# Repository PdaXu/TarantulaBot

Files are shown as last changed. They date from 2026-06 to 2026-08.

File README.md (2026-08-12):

<div align="center">

# 🕷️ TarantulaBot

**A Bio-Inspired Quadrupedal Wall-Climbing Robot with Electromagnetic Adhesion and a Soft Manipulator**

*仿生四足爬壁机器人 · 电磁吸附 · 软体机械手*

<!-- 图1：整机照片（机器人贴在钢面上工作）。放这里当 hero 图，第一眼抓人。 -->
<!-- IMAGE 1: Hero shot — the robot adhered to the steel wall. This is the first thing visitors see. -->
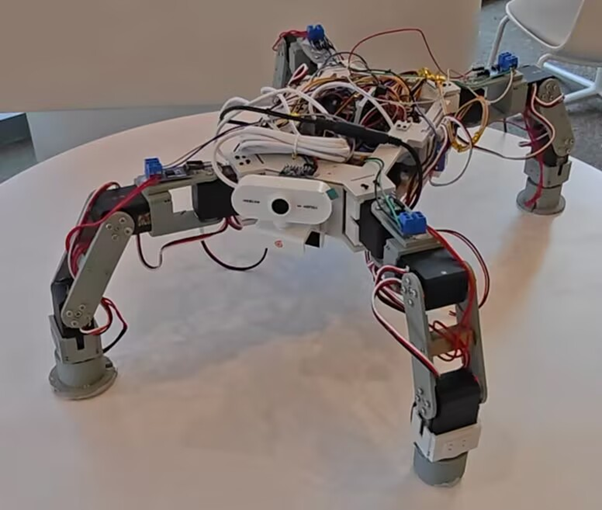
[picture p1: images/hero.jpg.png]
TarantulaBot


[English](#english) · [中文](#中文)

</div>

---

## English

### Overview

TarantulaBot is a bio-inspired quadrupedal wall-climbing robot designed to inspect and interact with ferromagnetic vertical structures such as steel towers, tanks, and I-beams. Unlike most wall-climbing platforms that are limited to passive inspection, TarantulaBot combines **legged climbing** with an **onboard soft manipulator**, so it can both traverse a surface and grasp small objects on it.

The platform integrates four subsystems on a two-tier control architecture: **the Orange Pi 5 decides, the ESP32 executes.**

<!-- 图2：系统架构框图（Orange Pi / ESP32 两层）。放在 Overview 下面，帮读者建立整体认知。 -->
<!-- IMAGE 2: System architecture diagram (two-tier Orange Pi / ESP32). Anchors the reader's mental model. -->
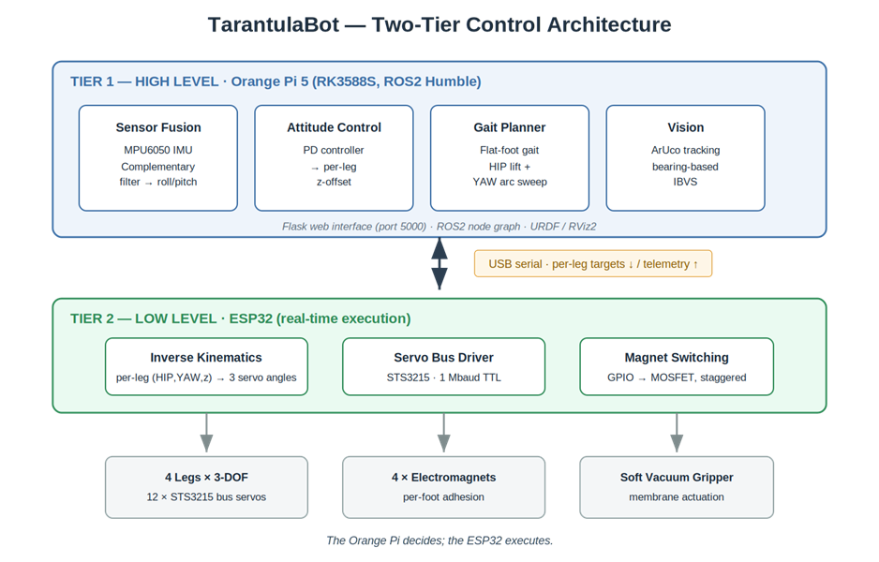
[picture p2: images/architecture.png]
System Architecture


### Key Features

- **12-DOF quadruped** — 4 legs × 3-DOF, driven by Feetech STS3215 bus servos
- **Flat-foot constrained gait** — ankle held vertical so the flat foot stays flush; each step is a HIP lift + YAW arc sweep
- **IMU attitude stabilization** — MPU6050 + complementary filter + PD, distributing a body-tilt error into per-leg height offsets (recovers a ~10° disturbance to level in ~0.40 s)
- **Per-foot electromagnetic adhesion** — MOSFET-switched, staggered activation, flyback-protected; handoff synchronized to the swing-to-stance transition
- **ArUco bearing-based visual servoing** — track a marker with no camera calibration
- **Soft vacuum-membrane manipulator** — grasps small irregular objects (keys, screws)
- **Flask web interface** — dark-theme control panel, bilingual toggle, per-leg magnet test, auto-reconnecting serial

### Demo

<!-- 图3：斜面爬行照片（标注角度 30–45°）。展示核心能力。 -->
<!-- IMAGE 3: Robot climbing the inclined steel plate (annotate 30–45°). Shows the core capability. -->
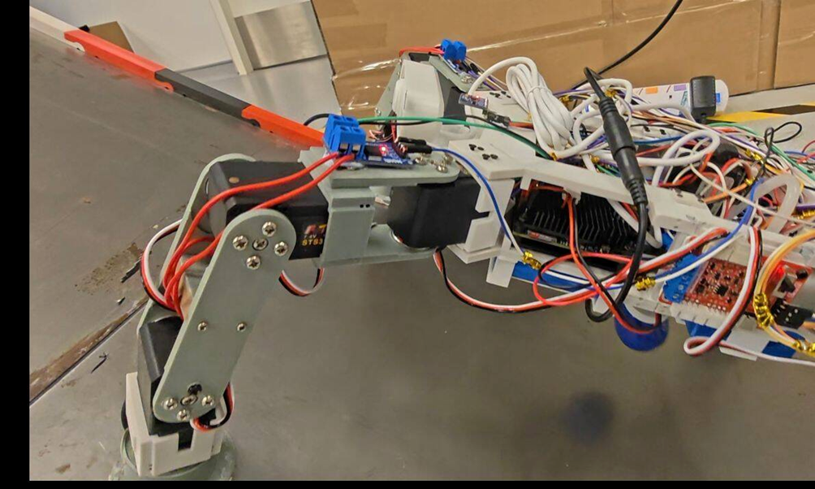
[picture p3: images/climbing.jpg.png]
Climbing demo


<!-- 图4：软夹爪抓取特写（钥匙/螺丝）。展示操作能力。 -->
<!-- IMAGE 4: Soft gripper holding a key / screw. Shows manipulation. -->
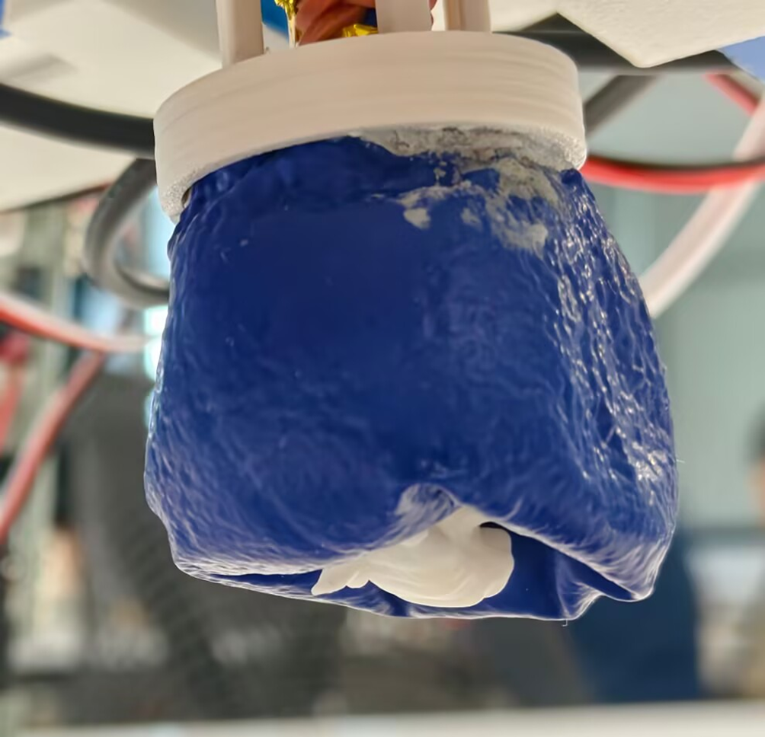
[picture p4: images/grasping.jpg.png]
Grasping demo


> 📹 A demo video is available here: `docs/demo.mp4` *(or link to your video)*

### How It Works

**Flat-foot constrained gait.** The feet are flat pads, not point contacts — a flat pad only adheres when its face is parallel to the wall. The ankle is therefore held vertical, and locomotion is produced by lifting the leg (HIP) and sweeping it in a YAW arc to the next footfall, rather than translating the foot in a straight line. Steering is differential: the left and right legs sweep by different amounts.

**Attitude control.** An MPU6050 is fused with a complementary filter (α ≈ 0.98) to estimate roll and pitch. A per-axis PD controller converts the tilt error into per-leg vertical offsets — the low side extends and the high side retracts, levelling the body since it cannot rotate itself.

<!-- 图5：IMU 姿态恢复曲线（roll/pitch 随时间，标 <1s）。有实测数据的图最有说服力。 -->
<!-- IMAGE 5: Measured PD attitude-recovery curve. Real data is the most convincing figure in the repo. -->
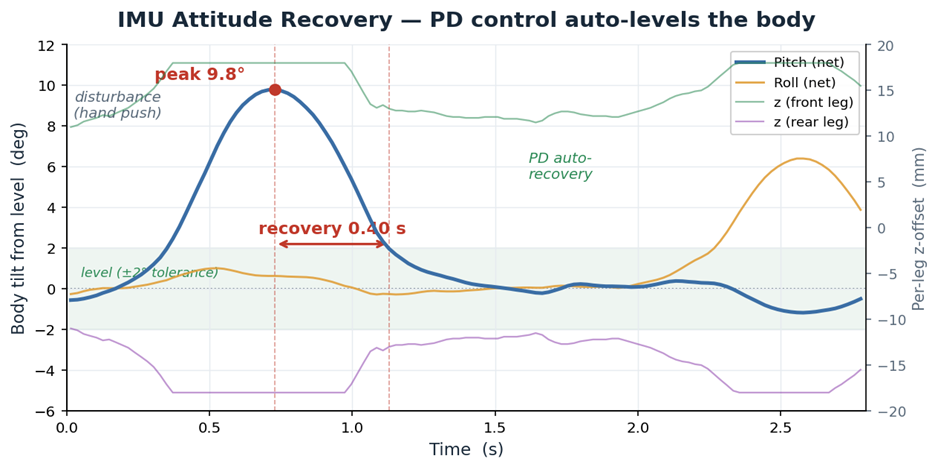
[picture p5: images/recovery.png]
Attitude recovery


**Visual servoing.** ArUco marker tracking uses the marker's horizontal pixel offset from image center as a heading error and drives it to zero — no camera intrinsics needed, because only alignment matters, not distance.

### Repository Structure

```
TarantulaBot/
├── firmware/          # ESP32 firmware (Arduino C++): servo bus + magnet switching
├── orangepi/          # High-level control (Python): IMU PD, gait, ArUco, Flask
│   ├── pid_ctrl.py    # IMU attitude PD controller
│   ├── app.py         # Flask web interface
│   └── ...
├── cad/               # 3D models (SolidWorks / STL) for legs and body plate
├── docs/              # Report, images, diagrams
└── README.md
```
> 按你的实际目录调整；上面是建议结构。

### Hardware

| Component | Detail |
|---|---|
| Compute (high-level) | Orange Pi 5 (RK3588S, ROS2 Humble) |
| Controller (low-level) | ESP32 (WROOM-32) |
| Servos | 12 × Feetech STS3215 (1 Mbaud TTL bus) |
| Adhesion | 4 × 12 V electromagnets, N-MOSFET switching, flyback diodes |
| IMU | MPU6050 (I²C) |
| Manipulator | Soft vacuum-membrane gripper + miniature pump |
| Structure | 3D-printed (PLA); SolidWorks source in `cad/` |

### Getting Started

```bash
# On the Orange Pi 5
git clone https://github.com/<your-username>/TarantulaBot.git
cd TarantulaBot/orangepi
pip install -r requirements.txt

# Flash firmware/ to the ESP32 via Arduino IDE (SCServo library required)

# Run the web control interface
python3 app.py
# then open http://<orangepi-ip>:5000 in a browser
```
> 具体命令按你的实际代码补全。

### Status & Limitations

TarantulaBot has been validated on flat ground and inclined steel up to **30–45°**, with reliable adhesion, attitude recovery, and soft-gripper grasping. **Full vertical (90°) wall-climbing was attempted but not yet achieved** — currently limited by adhesion-handoff timing, dynamic load transfer during leg swing, and structural rigidity under shear. This is the primary target for the next iteration.

### Team

**Team XD** — Xu Chenfei · Xu Pandeng
Singapore University of Technology and Design (SUTD) · Robotics and Automation (MTD)
Mentor: Prof. Pablo Valdivia y Alvarado

### License

Released under the MIT License — see [LICENSE](LICENSE). *（如果你想用别的许可，告诉我改）*

---

## 中文

### 项目简介

TarantulaBot 是一款仿生四足爬壁机器人,面向钢塔、储罐、工字梁等**铁磁性垂直结构**的巡检与作业。不同于大多数只能被动巡检的爬壁平台,TarantulaBot 把**足式攀爬**与**机载软体机械手**结合在一起——既能在表面移动,又能抓取表面上的小物件。

整机由四个子系统组成,采用两层控制架构:**Orange Pi 5 负责决策,ESP32 负责执行。**

<!-- 系统架构框图同上（图2） -->

### 核心特性

- **12 自由度四足** —— 4 腿 × 3 自由度,Feetech STS3215 总线舵机驱动
- **平足约束步态** —— 踝关节保持垂直,让平底足始终平贴表面;每步为 HIP 抬升 + YAW 弧形扫动
- **IMU 姿态稳定** —— MPU6050 + 互补滤波 + PD,将本体倾斜误差分配为每条腿的高度偏移(约 10° 扰动可在 ~0.40s 内回稳)
- **足端电磁吸附** —— MOSFET 开关、交错激活、flyback 保护;吸附时序严格同步到摆动相→支撑相切换
- **ArUco 方位视觉伺服** —— 无需相机标定即可跟踪标记
- **软体真空膜机械手** —— 抓取钥匙、螺丝等小型不规则物体
- **Flask 网页控制界面** —— 深色主题、中英切换、每条腿电磁铁独立测试、串口自动重连

### 演示

<!-- 斜面爬行图（图3）、软夹爪抓取图（图4）同上 -->

> 📹 演示视频:`docs/demo.mp4`（或替换成你的视频链接）

### 工作原理

**平足约束步态。** 足底是平垫而非点接触——平垫只有在与墙面平行时才能吸附。因此踝关节保持垂直,迈步靠抬腿(HIP)+ YAW 弧扫到下一落点实现,而不是让足直线平移。转向采用左右腿差速扫动。

**姿态控制。** MPU6050 经互补滤波(α ≈ 0.98)估计 roll/pitch,每轴 PD 控制器把倾斜误差转成每条腿的垂直偏移——低的一侧伸长、高的一侧缩短,靠不等高把本体撑平(本体自身无法旋转)。

<!-- IMU 姿态恢复曲线（图5）同上 -->

**视觉伺服。** ArUco 标记跟踪以标记中心相对图像中心的水平像素偏移作为朝向误差并将其归零——因为只关心对准、不关心距离,所以不需要相机内参。

### 目录结构

```
TarantulaBot/
├── firmware/          # ESP32 固件（Arduino C++）：舵机总线 + 电磁铁开关
├── orangepi/          # 上位机控制（Python）：IMU PD、步态、ArUco、Flask
│   ├── pid_ctrl.py    # IMU 姿态 PD 控制器
│   ├── app.py         # Flask 网页界面
│   └── ...
├── cad/               # 三维模型（SolidWorks / STL）：腿部与机身板
├── docs/              # 报告、图片、示意图
└── README.md
```
> 请按你的实际目录调整。

### 硬件清单

| 部件 | 说明 |
|---|---|
| 主控（高层） | Orange Pi 5（RK3588S，ROS2 Humble） |
| 下位机（底层） | ESP32（WROOM-32） |
| 舵机 | 12 × Feetech STS3215（1 Mbaud TTL 总线） |
| 吸附 | 4 × 12 V 电磁铁，N-MOSFET 开关，flyback 二极管 |
| IMU | MPU6050（I²C） |
| 机械手 | 软体真空膜夹爪 + 微型气泵 |
| 结构 | 3D 打印（PLA）；SolidWorks 源文件见 `cad/` |

### 快速开始

```bash
# 在 Orange Pi 5 上
git clone https://github.com/<你的用户名>/TarantulaBot.git
cd TarantulaBot/orangepi
pip install -r requirements.txt

# 用 Arduino IDE 将 firmware/ 烧录到 ESP32（需 SCServo 库）

# 运行网页控制界面
python3 app6.py
# 浏览器打开 http://<orangepi-ip>:5000
```
> 具体命令按你的实际代码补全。

### 现状与局限

TarantulaBot 已在平地和倾斜钢面(**30–45°**)上验证,吸附可靠,姿态可恢复,软夹爪抓取成功。**90° 垂直爬墙已尝试但尚未完全实现**——当前受限于吸附时序、摆动相动态载荷转移、以及剪切载荷下的结构刚性,这是下一代的首要目标。

### 团队

**Team XD** —— 徐晨飞 · 徐磐登
新加坡科技设计大学(SUTD)· 机器人与自动化(MTD)
导师:Prof. Pablo Valdivia y Alvarado

### 许可

采用 MIT 许可证,见 [LICENSE](LICENSE)。

</div>

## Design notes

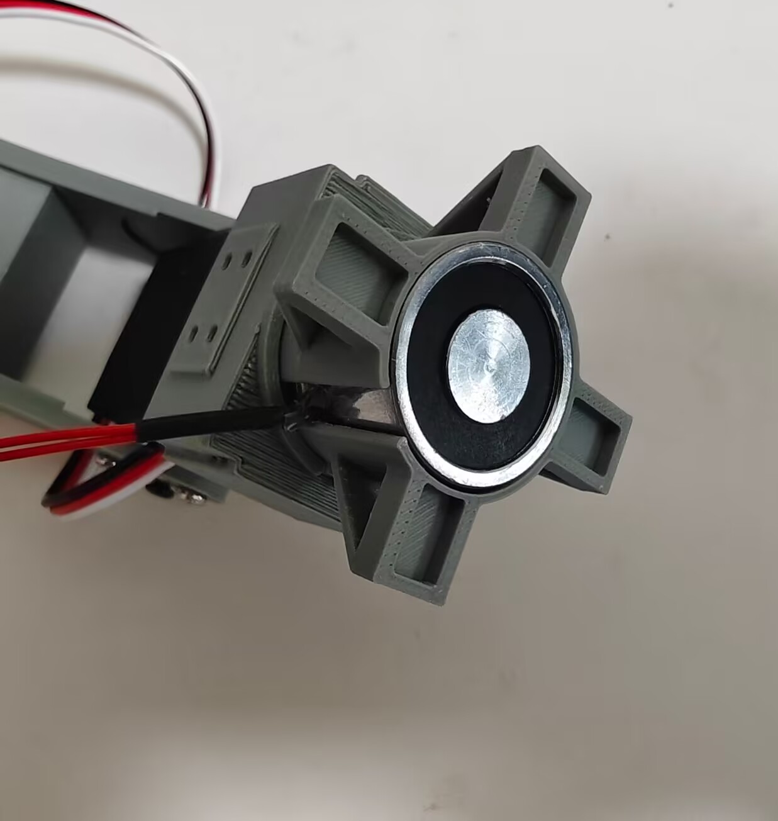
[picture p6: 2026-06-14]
assets/Foot.jpg

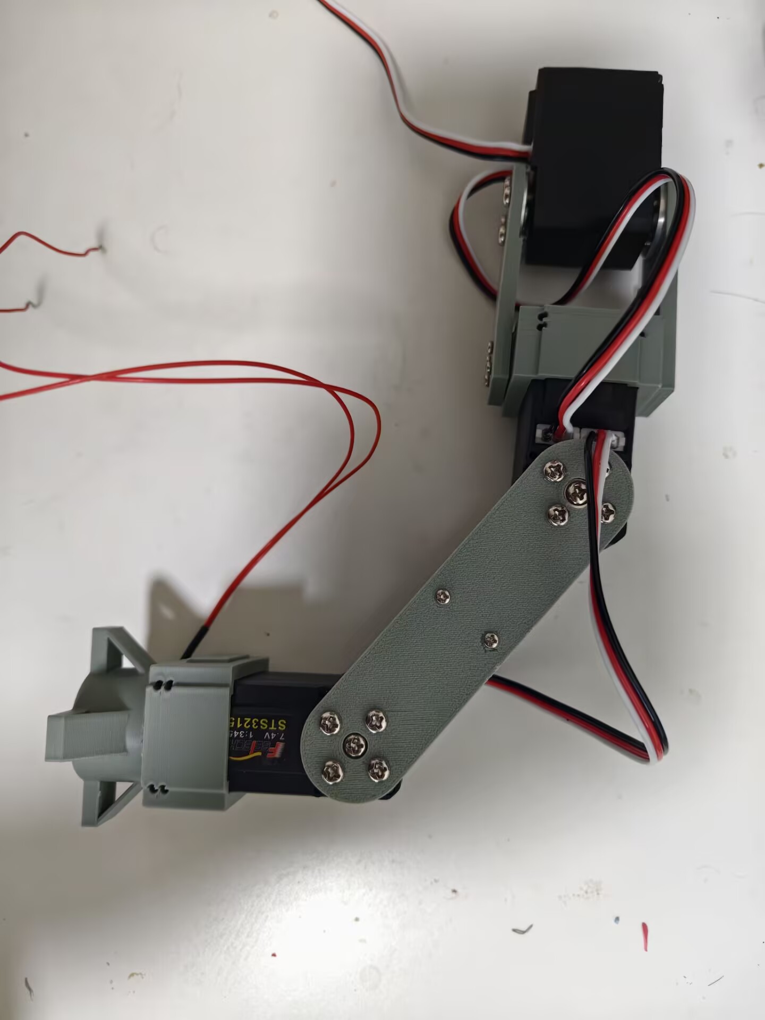
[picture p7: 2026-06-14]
assets/WholeoneLeg.jpg

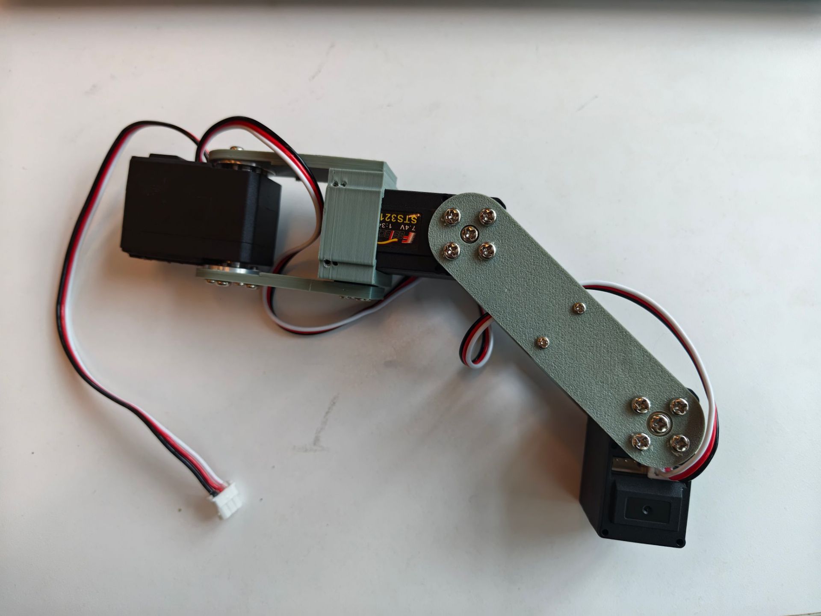
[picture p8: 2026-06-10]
assets/oneLeg1.jpg

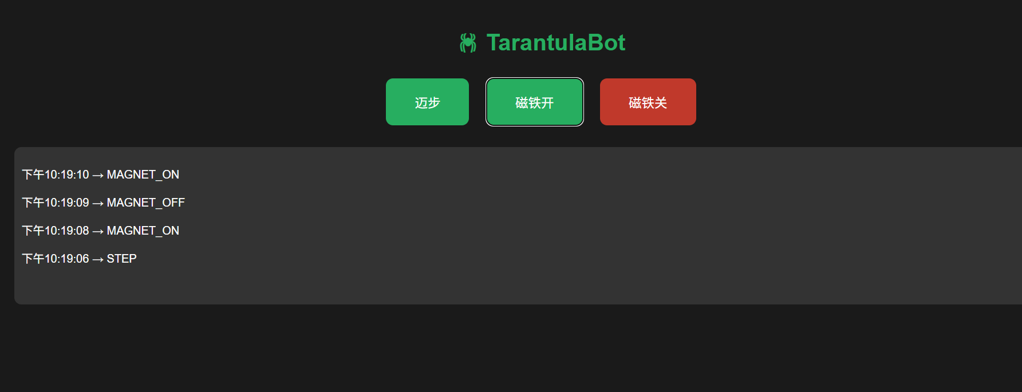
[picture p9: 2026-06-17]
assets/web1.png

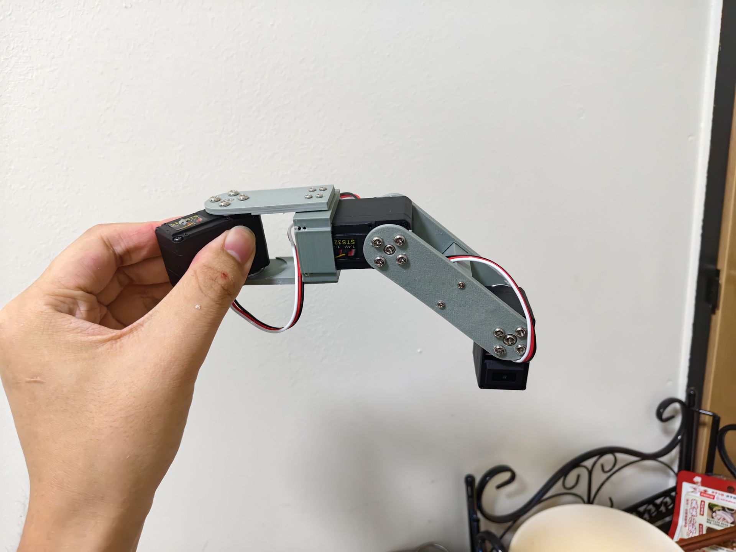
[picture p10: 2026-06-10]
assets/oneLeg.jpg

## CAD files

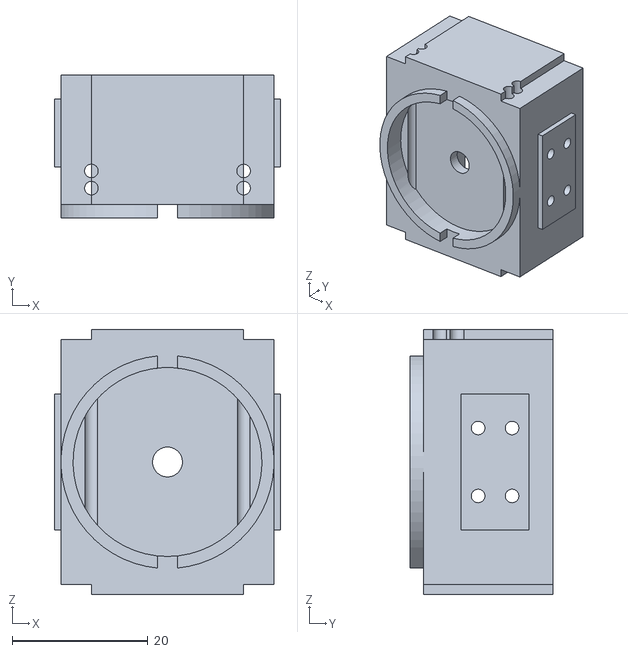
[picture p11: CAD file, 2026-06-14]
oneLegMoudle/FootMBox1.STL
33.3 x 21.0 x 39.0

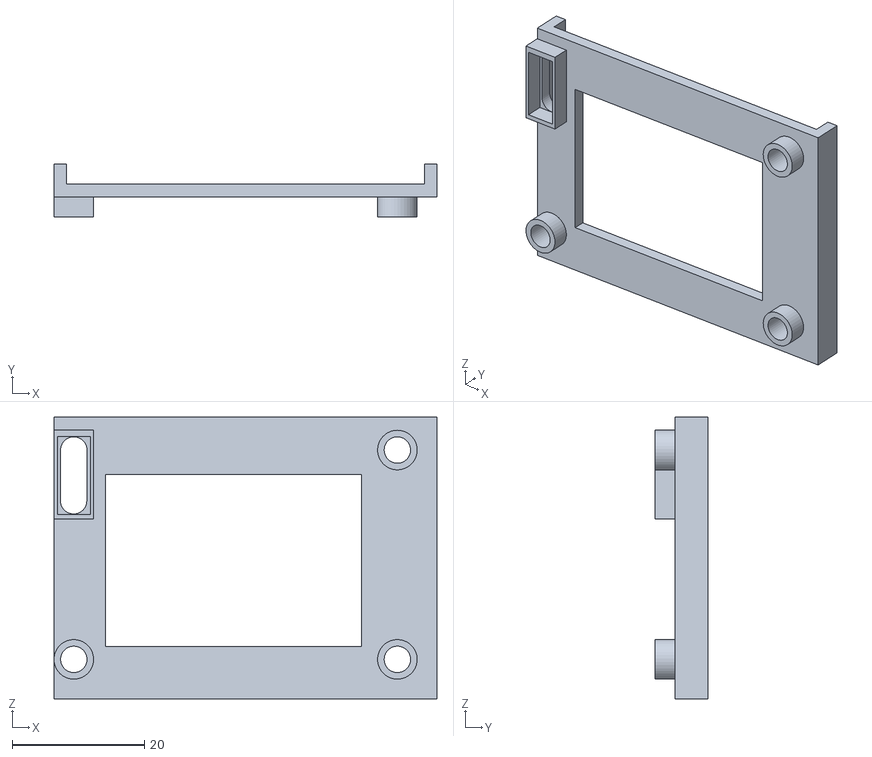
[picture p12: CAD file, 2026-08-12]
Whole3DModels/feetechB.STL
58.0 x 8.00 x 42.7

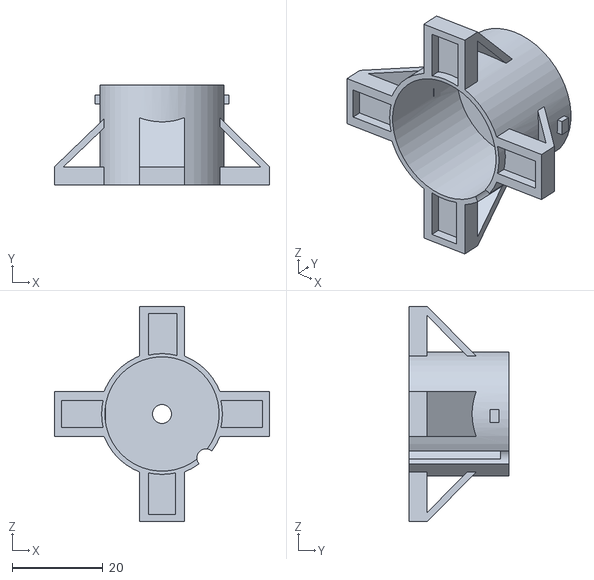
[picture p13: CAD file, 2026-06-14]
oneLegMoudle/fOOT.STL
47.4 x 22.0 x 47.4

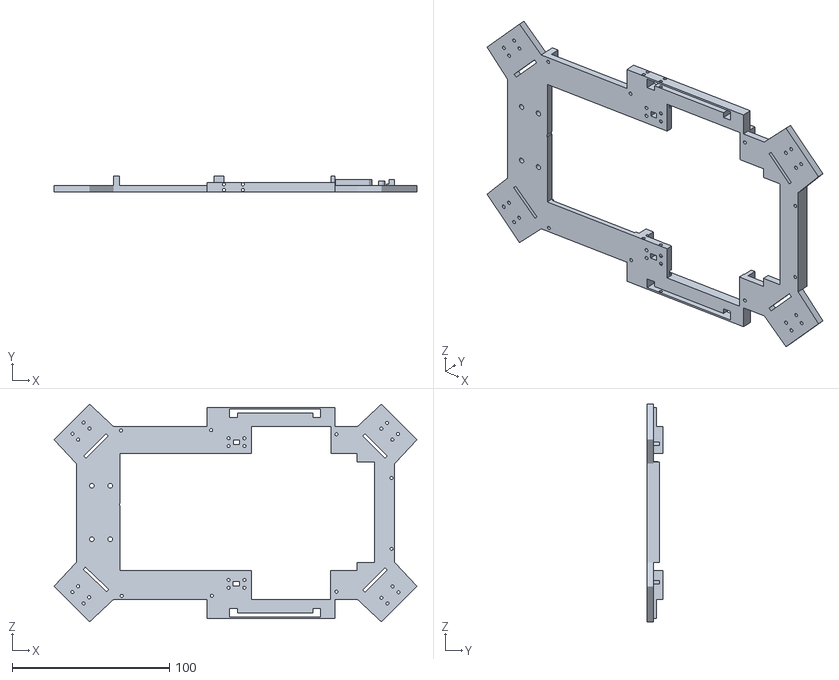
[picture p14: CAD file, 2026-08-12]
Whole3DModels/bodyTop.STL
230.6 x 10.0 x 138.3

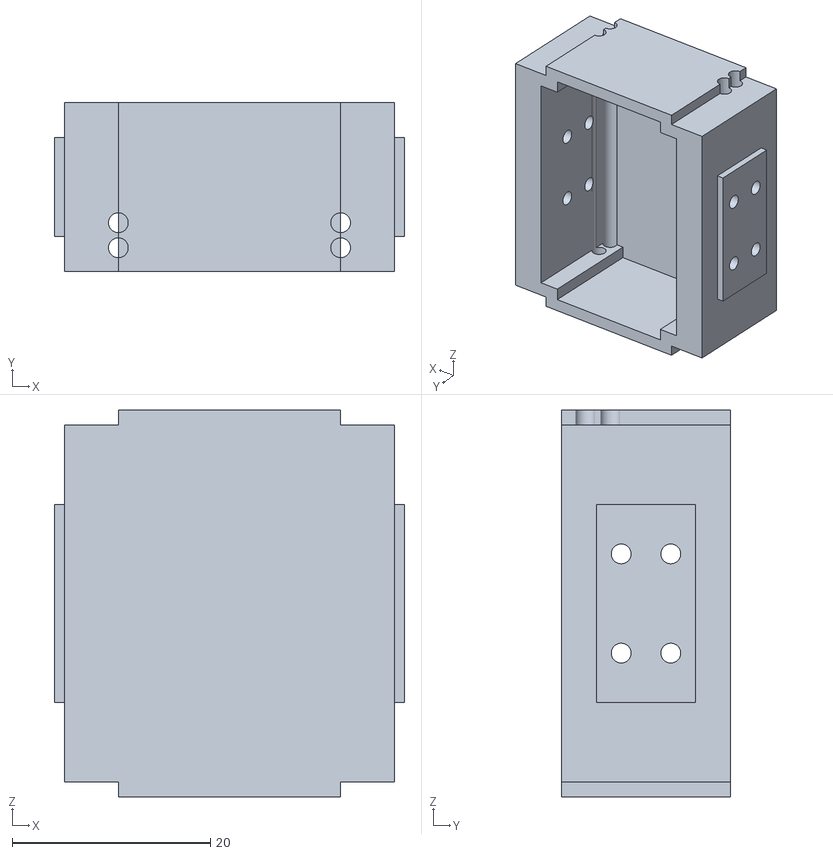
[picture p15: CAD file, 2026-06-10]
oneLegMoudle/MBox1.STL
35.3 x 17.0 x 39.0

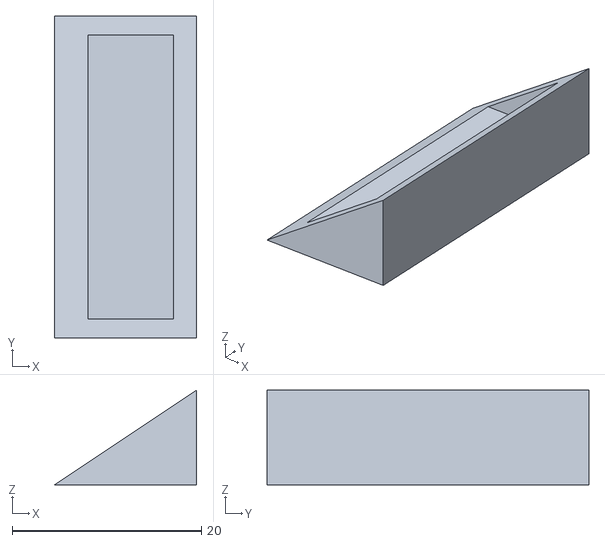
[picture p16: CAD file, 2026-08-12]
Whole3DModels/cameraSupport.STL
15.0 x 34.0 x 10.0

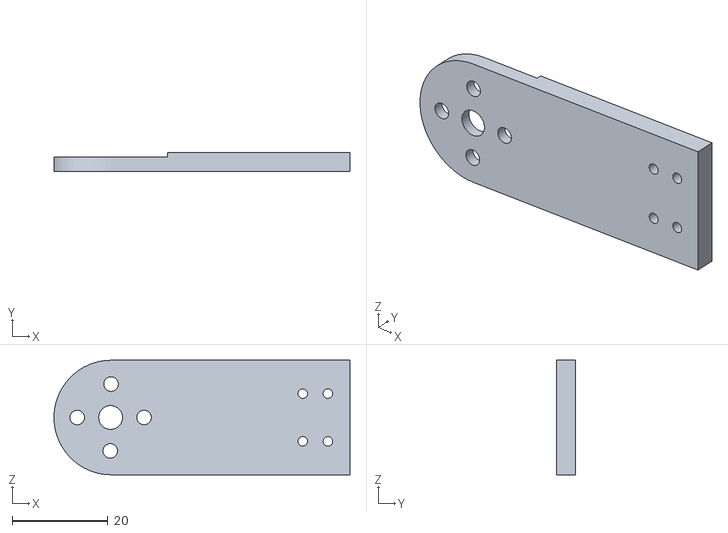
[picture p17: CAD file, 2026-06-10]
oneLegMoudle/leghang1.STL
62.0 x 4.00 x 24.0

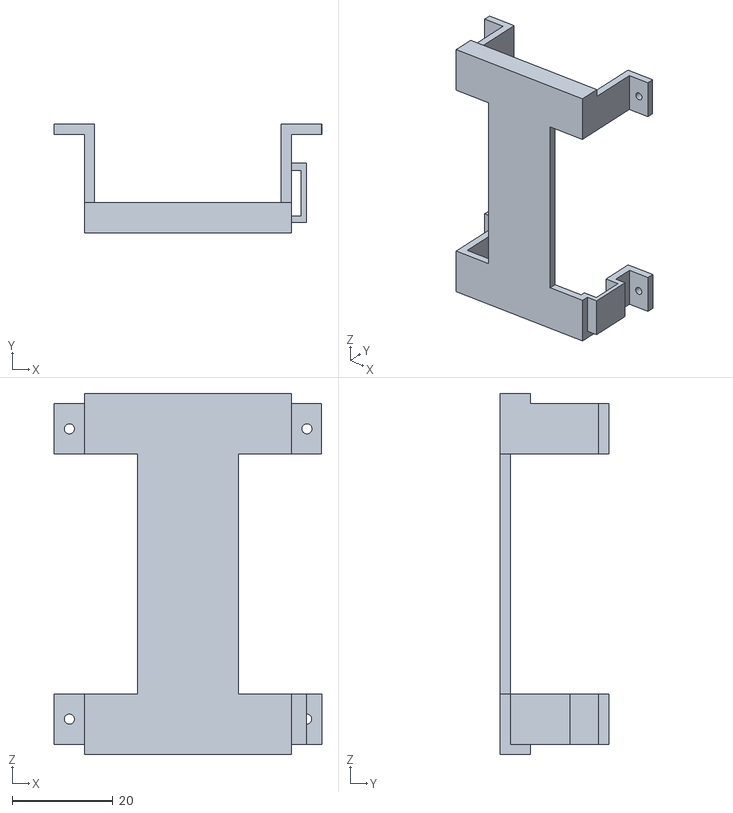
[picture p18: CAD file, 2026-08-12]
Whole3DModels/batteryBoxS_n.STL
53.0 x 21.5 x 71.5

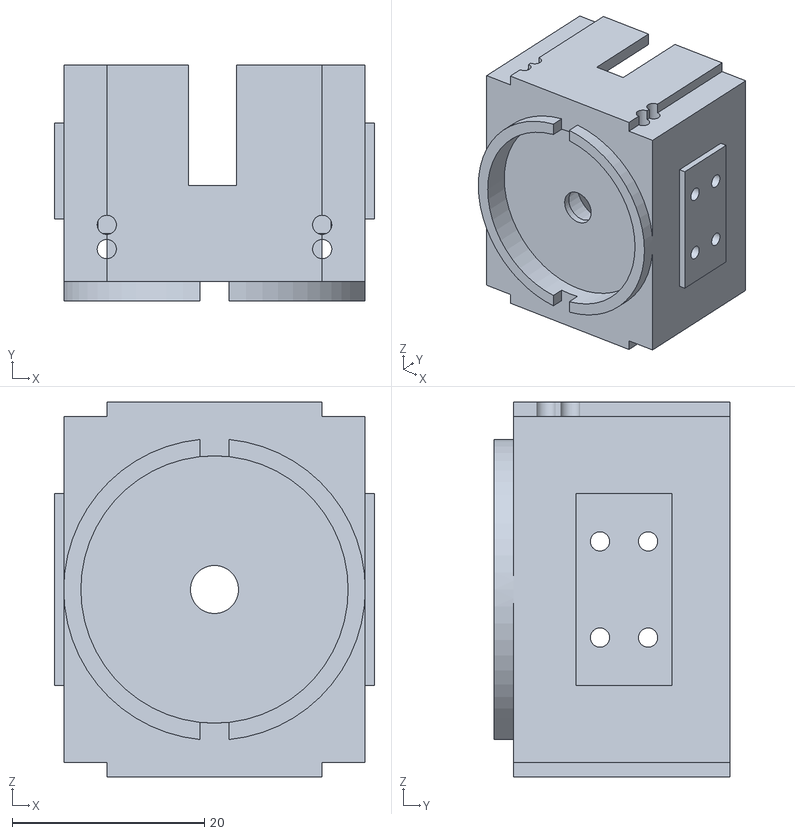
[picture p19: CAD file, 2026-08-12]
Whole3DModels/FootMBox3.STL
33.3 x 24.5 x 39.0

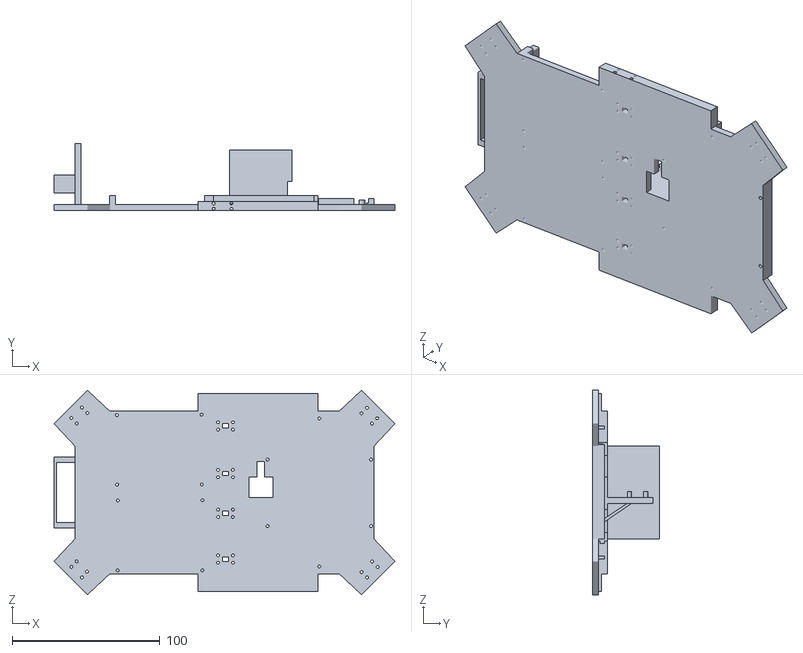
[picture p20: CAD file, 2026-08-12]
Whole3DModels/bodyBV1.STL
230.6 x 45.3 x 138.3

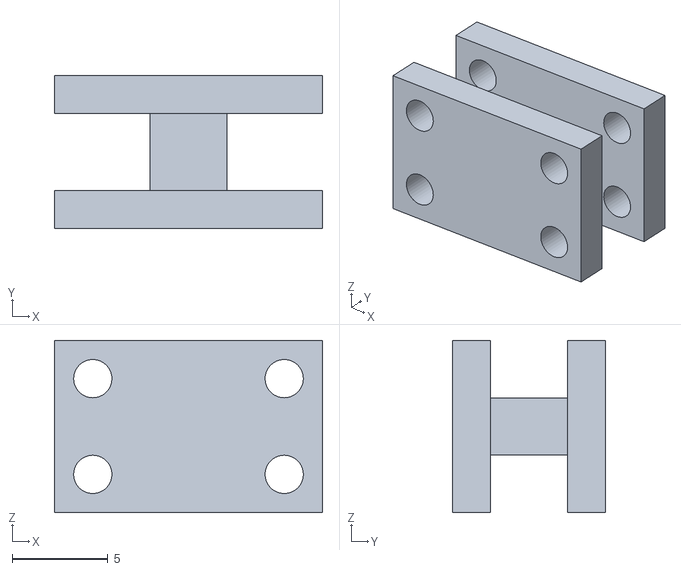
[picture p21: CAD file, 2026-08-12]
Whole3DModels/C1.STL
14.0 x 8.00 x 9.00

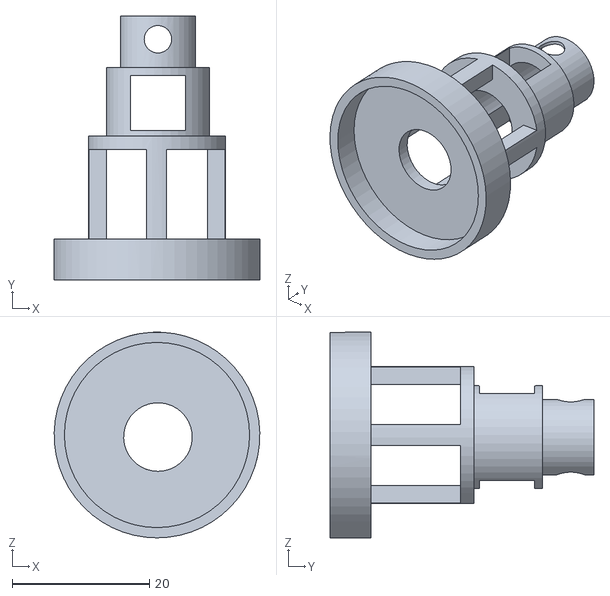
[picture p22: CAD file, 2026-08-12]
Whole3DModels/hand.STL
30.0 x 38.5 x 30.0

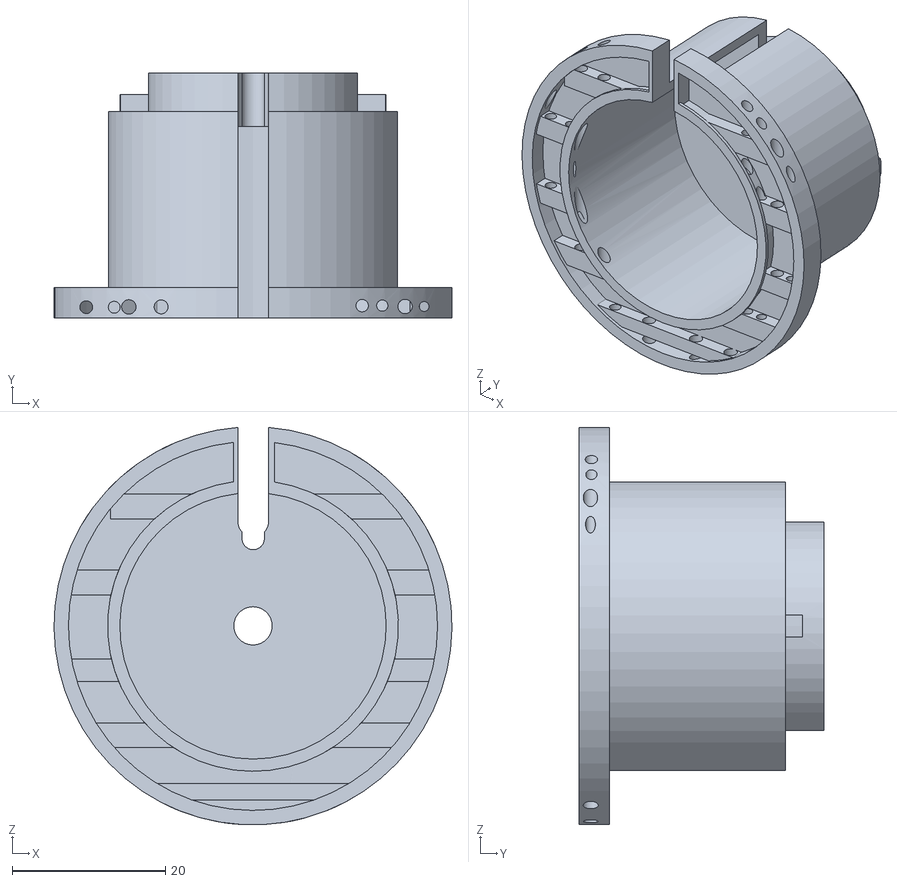
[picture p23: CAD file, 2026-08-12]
Whole3DModels/foot20V.STL
52.0 x 32.0 x 51.9

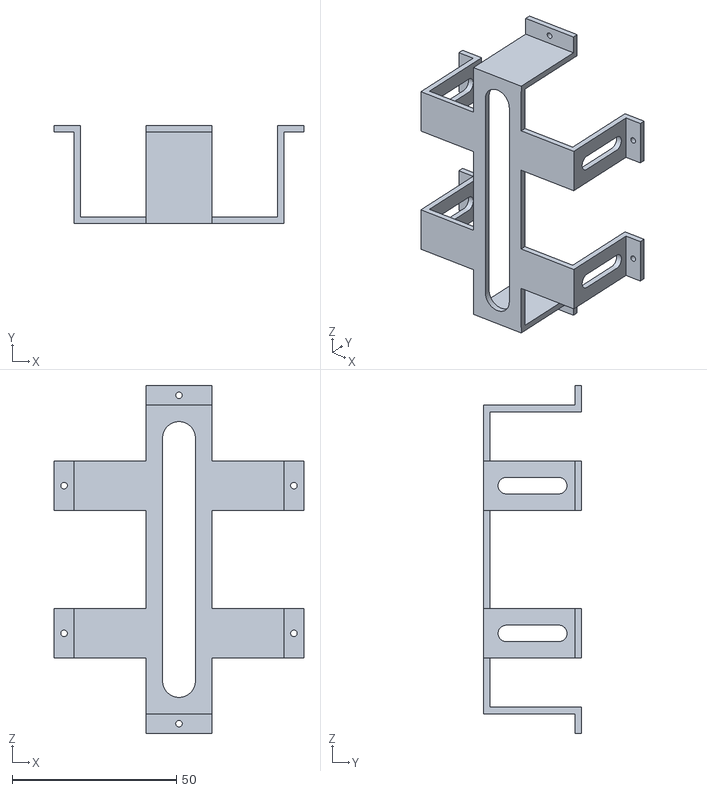
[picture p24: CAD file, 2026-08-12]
Whole3DModels/batteryBox12.STL
76.0 x 30.0 x 106.0

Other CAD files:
Whole3DModels/leghang1.STL
Whole3DModels/batteryBoxS.STL
Whole3DModels/MBoxN.STL
Whole3DModels/legTop.STL
Whole3DModels/legMid.STL
Whole3DModels/leghang2.STL

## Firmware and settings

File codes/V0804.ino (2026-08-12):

/*
 * TarantulaBot 固件 - 平脚步态 + 姿态偏移 + 四路电磁铁爬墙版 + 原地转/平移
 *
 * ADJ z0 z1 z2 z3  (mm, 顺序LF LB RF RB, ±20) 由Orange Pi PID下发, 失联500ms清零
 * 四路电磁铁: LF=16 LB=14 RF=13 RB=12
 * CLIMB模式: wave时序 + 磁铁配合(摆动腿释放, 其余吸附, 恒>=3磁铁吸墙)
 *
 * 运动模式(moveMode, 用于FWD/BACK/LEFT/RIGHT, 不影响CLIMB):
 *   0 前进/后退: 四腿同向摆动
 *   1 原地转:   左侧(LF,LB) vs 右侧(RF,RB) 反向摆动 -> 纯自转,不前进 (已实测修正方向)
 *   (曾尝试横向平移模式, 实测为原地踏步, 单自由度YAW摆动架构无法合成横向分量, 已移除;
 *    需要转向移动时用"原地转+前进"组合实现)
 *
 * ID: LF 1/2/3  LB 4/5/6  RF 7/8/9  RB 10/11/12 (YAW, HIP, ANKLE)
 * 平脚约束: knee = -90 - hip
 */
#include <Arduino.h>
#include <SCServo.h>
#include <math.h>

SMS_STS st1;
SMS_STS st2;

// 四路电磁铁 (按腿索引 LF LB RF RB)
#define MAG_LF    16
#define MAG_LB    14
#define MAG_RF    13
#define MAG_RB    12
const int MAG_PIN[4] = {MAG_LF, MAG_LB, MAG_RF, MAG_RB};

#define PUMP_PIN  25
#define BOOT_PIN  0
#define ACT_IN1   32
#define ACT_IN2   33

const float L1 = 76.0, L2 = 72.0, L3 = 61.0;
const float CNT_PER_DEG = 4096.0/360.0;
const float RAD2DEG = 57.29578;
const float DEG2RAD = 0.0174533;

struct Calib { int cnt0; float ang0; int sign; };
struct Leg {
  const char* name; SMS_STS* bus;
  int idYaw, idHip, idKnee;
  float hipy;
  Calib yaw, hip, knee;
};

// 标定 (用户最新实测版)
Leg legs[4] = {
  {"LF", &st1,  1, 2, 3,  +1, {1999,0,-1}, {1861,-45,+1}, {2153,-41,+1}},
  {"LB", &st1,  4, 5, 6,  -1, {1955,0,+1}, {1251,-45,+1}, {1687,-41,+1}},
  {"RF", &st2,  7, 8, 9,  -1, {1975,0,-1}, {1002,-45,+1}, {1880,-41,+1}},
  {"RB", &st2, 10,11,12,  +1, {2058,0,+1}, {1202,-45,+1}, {1752,-41,+1}},
};

// ===== 步态参数 =====
float STAND_HIP  = -45.0;
float LEG_TRIM[4]  = {4.0, 4.0, 4.0, 4.0};   // 度, 四腿独立踝竖直补偿 (LF,LB,RF,RB)
float LEG_REACH[4] = {22.0, 26.0, 24.0, 25.0};   // mm, 四腿独立伸展量 (LF,LB,RF,RB) 实测标定
float STRIDE_DEG = 16.0;
float STEP_H     = 30.0;   // mm, 抬腿高度(trot用)
float WAVE_STEP_H = 50.0;  // mm, wave专用抬腿高度(比trot抬更高, 应对斜坡/爬墙场景)
float WAVE_SWING = 0.20;
float TROT_DUTY  = 0.35;
float TROT_SAG   = 8.0;
float WAVE_RATE  = 0.028;
float TROT_RATE  = 0.020;
int   mode = 0;            // 0=站立 1=trot 2=wave 3=climb 4=strafe(左右平移,支持wave/trot两种时序)
bool  lastPressed = false;

int   dirSign = +1;      // 仅CLIMB沿用
float turnBias = 0.0;    // 仅CLIMB沿用

// FWD/BACK/LEFT/RIGHT 用的独立方向系统 (原地转)
int   moveMode = 0;      // 0=前进后退 1=原地转
int   moveSign = +1;     // 该模式下的方向

// 全向步态(mode=5)专用: 基于实测LEG_DIR_DEG, 一个公式覆盖FWD/BACK/STRAFE
float moveDirDeg = 0.0;  // 目标移动方向(clock角度, 0=前进 180=后退 90=右移 270=左移)
int   omniGait   = 2;    // 1=trot 2=wave

// ===== 姿态偏移 (Orange Pi PID下发) =====
float zOff[4] = {0,0,0,0};
unsigned long lastAdjMs = 0;
const unsigned long ADJ_TIMEOUT = 500;
const float ZOFF_MAX = 20.0;

// 错峰控制: 多个磁铁不同时通断, 每个间隔MAG_STAGGER_MS, 摊平峰值电流
// 改为非阻塞版: 原来用delay()会卡住主循环480ms, 期间舵机收不到新指令表现为"卡顿变慢"
// 现在用millis()记录状态, loop()正常跑, gaitStep/omniStep不受影响
const int MAG_STAGGER_MS = 120;
bool magSeqActive = false;
int  magSeqTarget = HIGH;      // 本次序列是要全开(HIGH)还是全关(LOW)
int  magSeqIdx = 0;
unsigned long magSeqLastMs = 0;

void magAllOn()  { magSeqActive=true; magSeqTarget=HIGH; magSeqIdx=0; magSeqLastMs=millis(); }
void magAllOff() { magSeqActive=true; magSeqTarget=LOW;  magSeqIdx=0; magSeqLastMs=millis(); }

void magSeqUpdate() {
  if (!magSeqActive) return;
  if (magSeqIdx == 0 || millis() - magSeqLastMs >= (unsigned long)MAG_STAGGER_MS) {
    if (magSeqIdx < 4) {
      digitalWrite(MAG_PIN[magSeqIdx], magSeqTarget);
      magSeqIdx++;
      magSeqLastMs = millis();
    } else {
      magSeqActive = false;
    }
  }
}

int angToCnt(Calib &c, float ang_deg) {
  return (int)round(c.cnt0 + c.sign*(ang_deg - c.ang0)*CNT_PER_DEG);
}

void flatFootMove(int i, float yawDeg, float z, int speed) {
  Leg &lg = legs[i];
  z -= LEG_REACH[i];   // 正值=该腿多往下/往外伸展(跨面时脚不够长用)
  float sinHip = (z + L3) / L2;
  sinHip = constrain(sinHip, -1.0, 1.0);
  float hipDeg  = asin(sinHip) * RAD2DEG;
  float kneeDeg = -90.0 - hipDeg + LEG_TRIM[i];   // 四腿独立踝补偿, 不再分组
  lg.bus->WritePosEx(lg.idYaw,  angToCnt(lg.yaw,  yawDeg),  speed, 50);
  lg.bus->WritePosEx(lg.idHip,  angToCnt(lg.hip,  hipDeg),  speed, 50);
  lg.bus->WritePosEx(lg.idKnee, angToCnt(lg.knee, kneeDeg), speed, 50);
}

float standZ() { return L2 * sin(STAND_HIP*DEG2RAD) - L3; }

void standAll(int speed=800) {
  for (int i=0;i<4;i++) flatFootMove(i, 0, standZ() + zOff[i], speed);
}

int swingDir(int i) { return (legs[i].hipy > 0) ? -1 : +1; }

void legTarget(int i, float phase, int gait, float &yawDeg, float &z) {
  bool sw; float s;
  if (gait == 1) {
    float grp = (i==0 || i==3) ? 0.0 : 0.5;
    float lp = fmod(phase + grp, 1.0);
    sw = lp < TROT_DUTY;
    s = sw ? lp/TROT_DUTY : (lp-TROT_DUTY)/(1.0-TROT_DUTY);
  } else {
    float seq;
    if (i==1) seq=0;
    else if (i==0) seq=1;
    else if (i==3) seq=2;
    else seq=3;
    float lp = fmod(phase - seq/4.0 + 1.0, 1.0);
    sw = lp < WAVE_SWING;
    s = sw ? lp/WAVE_SWING : (lp-WAVE_SWING)/(1.0-WAVE_SWING);
  }

  // 两种运动模式的振幅分配:
  //   0 前进/后退: 四腿同向摆动
  //   1 原地转:   左侧(LF,LB) vs 右侧(RF,RB) 反向摆动 -> 纯自转
  // 注: 曾尝试moveMode=2(前后腿反向=平移), 实测为原地踏步(单自由度YAW摆动架构
  //     无法独立合成横向分量), 已移除。需要平移时用"原地转+前进"组合实现转向。
  float amp;
  if (moveMode == 1) {
    float side = (i==0 || i==1) ? -1.0 : +1.0;   // LF,LB=左侧  RF,RB=右侧 (已按实测翻转)
    amp = STRIDE_DEG * moveSign * side;
  } else {
    amp = STRIDE_DEG * moveSign;                  // 前进/后退
  }

  float q;
  z = standZ() + zOff[i];
  float stepH = (gait == 1) ? STEP_H : WAVE_STEP_H;
  if (sw) {
    q = (s - sin(2*M_PI*s)/(2*M_PI)) - 0.5;
    z += stepH * (1-cos(2*M_PI*s)) / 2;
  } else {
    q = 0.5 - s;
    if (gait == 1) z -= TROT_SAG;
  }
  yawDeg = swingDir(i) * amp * q * 2.0;
}

void gaitStep(int gait) {
  static float phase = 0;
  phase = fmod(phase + ((gait==1) ? TROT_RATE : WAVE_RATE), 1.0);
  int speed = 3400;
  for (int i=0;i<4;i++){
    float yawDeg, z;
    legTarget(i, phase, gait, yawDeg, z);
    flatFootMove(i, yawDeg, z, speed);
  }
  delay(40);
}

// ===== 爬墙步态: wave时序 + 磁铁配合 (未改动, 仍用dirSign/turnBias) =====
void climbStep() {
  static float phase = 0;
  phase = fmod(phase + WAVE_RATE, 1.0);
  int speed = 3400;

  for (int i=0;i<4;i++){
    float seq;
    if (i==1) seq=0;
    else if (i==0) seq=1;
    else if (i==3) seq=2;
    else seq=3;
    float lp = fmod(phase - seq/4.0 + 1.0, 1.0);
    bool sw = lp < WAVE_SWING;
    float s = sw ? lp/WAVE_SWING : (lp-WAVE_SWING)/(1.0-WAVE_SWING);

    if (sw) {
      if (s < 0.15) digitalWrite(MAG_PIN[i], LOW);   // 起摆释放, 时机正确(脚刚离墙)
      // 原来这里有 else if (s>0.85) 提前通电 —— 此时脚离墙面仍有约20%*STEP_H的气隙
      // (气隙对磁吸力极敏感, 提前通电基本吸不住), 这正是"交接打滑"的根源, 已删除
      // 改为完全依赖下面stance分支: 只有真正进入支撑相(脚已贴墙, 气隙=0)才通电
    } else {
      digitalWrite(MAG_PIN[i], HIGH);   // 支撑相开始瞬间=脚已贴墙, 此时通电才有效
    }

    float amp = STRIDE_DEG * dirSign;
    if (i==0 || i==1) amp *= (1.0 - turnBias);
    else              amp *= (1.0 + turnBias);

    float q, z = standZ() + zOff[i];
    if (sw) {
      q = (s - sin(2*M_PI*s)/(2*M_PI)) - 0.5;
      z += WAVE_STEP_H * (1-cos(2*M_PI*s)) / 2;
    } else {
      q = 0.5 - s;
    }
    float yawDeg = swingDir(i) * amp * q * 2.0;
    flatFootMove(i, yawDeg, z, speed);
  }
  delay(40);
}

// ===== 全向步态 (基于实测方向标定, 一个公式覆盖前进/后退/左移/右移) =====
// 每条腿的真实响应方向(clock角度制, 12点=0°=机头, 顺时针为正) - 2026-08实测标定:
//   LF=-15° LB=-165° RF=+45° RB=+135° (左右两侧明显不对称, 之前所有±1差动猜测
//   必然失败的根源就在这里 —— 几何本身不对称, 不存在简单的对称差动组合)
// 任意移动方向φ(clock角度), 每条腿振幅权重 = cos(该腿角度 - φ), 不再需要swingDir
const float LEG_DIR_DEG[4] = { -15.0, -165.0, 45.0, 135.0 };  // LF LB RF RB

void omniStep(float moveDirDeg, int gait) {
  static float phase = 0;
  phase = fmod(phase + ((gait==1) ? TROT_RATE : WAVE_RATE), 1.0);
  int speed = 3400;
  float phi = moveDirDeg * DEG2RAD;

  for (int i=0;i<4;i++){
    bool sw; float s;
    if (gait == 1) {
      float grp = (i==0 || i==3) ? 0.0 : 0.5;
      float lp = fmod(phase + grp, 1.0);
      sw = lp < TROT_DUTY;
      s = sw ? lp/TROT_DUTY : (lp-TROT_DUTY)/(1.0-TROT_DUTY);
    } else {
      float seq;
      if (i==1) seq=0;
      else if (i==0) seq=1;
      else if (i==3) seq=2;
      else seq=3;
      float lp = fmod(phase - seq/4.0 + 1.0, 1.0);
      sw = lp < WAVE_SWING;
      s = sw ? lp/WAVE_SWING : (lp-WAVE_SWING)/(1.0-WAVE_SWING);
    }

    float theta = LEG_DIR_DEG[i] * DEG2RAD;
    float weight = cos(theta - phi);      // 该腿对目标方向的贡献权重, 替代swingDir
    float amp = STRIDE_DEG * weight;

    float q, z = standZ() + zOff[i];
    float stepH = (gait == 1) ? STEP_H : WAVE_STEP_H;
    if (sw) {
      q = (s - sin(2*M_PI*s)/(2*M_PI)) - 0.5;
      z += stepH * (1-cos(2*M_PI*s)) / 2;
    } else {
      q = 0.5 - s;
      if (gait == 1) z -= TROT_SAG;
    }
    float yawDeg = amp * q * 2.0;          // 不再乘swingDir, weight已含正确符号
    flatFootMove(i, yawDeg, z, speed);
  }
  delay(40);
}

void actuatorStop(){ digitalWrite(ACT_IN1,LOW); digitalWrite(ACT_IN2,LOW); }

// ===== 单腿方向标定测试 (方案B第一步: 精确测量每条腿足端真实响应方向) =====
// 其余三腿保持站姿不动, 被测腿从yawDeg=-SWEEP摆到+SWEEP再摆回, 悬空往返
// 观察足端摆动方向对应的钟点(以机头=12点), 记录后用于计算完整2D步态
void testLegDir(int i) {
  const float SWEEP = 25.0;  // 度, 摆动幅度(适当放大方便观察)
  int speed = 800;
  float z = standZ();
  Serial.printf(">>> 测试 %s: 从-%.0f度摆到+%.0f度, 观察足端摆动方向(以机头=12点)\n",
                legs[i].name, SWEEP, SWEEP);
  flatFootMove(i, -SWEEP, z, speed); delay(1000);
  flatFootMove(i, +SWEEP, z, speed); delay(1200);
  flatFootMove(i, -SWEEP, z, speed); delay(1200);
  flatFootMove(i, 0, z, speed);      delay(800);
  Serial.printf("<<< %s 完成, 记录方向\n", legs[i].name);
}

bool parseAdj(String &cmd) {
  if (!cmd.startsWith("ADJ")) return false;
  float v[4];
  int idx = 3, n = 0;
  while (n < 4) {
    while (idx < (int)cmd.length() && cmd[idx]==' ') idx++;
    if (idx >= (int)cmd.length()) return false;
    int sp = cmd.indexOf(' ', idx);
    String tok = (sp<0) ? cmd.substring(idx) : cmd.substring(idx, sp);
    v[n++] = tok.toFloat();
    if (sp<0) break;
    idx = sp;
  }
  if (n < 4) return false;
  for (int i=0;i<4;i++) zOff[i] = constrain(v[i], -ZOFF_MAX, ZOFF_MAX);
  lastAdjMs = millis();
  return true;
}

void setup() {
  Serial.begin(115200);
  Serial1.begin(1000000, SERIAL_8N1, 19, 21);
  Serial2.begin(1000000, SERIAL_8N1, 22, 23);
  st1.pSerial=&Serial1; st2.pSerial=&Serial2;

  for(int i=0;i<4;i++){ pinMode(MAG_PIN[i],OUTPUT); digitalWrite(MAG_PIN[i],LOW); }
  pinMode(PUMP_PIN,OUTPUT);
  pinMode(BOOT_PIN,INPUT_PULLUP);
  pinMode(ACT_IN1,OUTPUT); pinMode(ACT_IN2,OUTPUT);
  digitalWrite(PUMP_PIN,LOW); actuatorStop();

  delay(1000);
  Serial.println("=== TarantulaBot 平脚步态 + 四路磁铁爬墙固件 (含原地转/平移) ===");
  standAll();
  delay(1000);
  magAllOn();
  Serial.println("站立完成, 四磁铁错峰吸附");
}

void loop() {
  magSeqUpdate();   // 非阻塞磁铁错峰序列推进, 不影响舵机指令时序

  if (Serial.available()) {
    String cmd = Serial.readStringUntil('\n'); cmd.trim();
    if (parseAdj(cmd)) {
      if (mode == 0) standAll(1500);
    }
    else if (cmd=="FWD"||cmd=="WALK"||cmd=="WAVE"){mode=5; moveDirDeg=0.0;   omniGait=2; Serial.println("前进(全向,wave)");}
    else if (cmd=="BACK")         {mode=5; moveDirDeg=180.0; omniGait=2; Serial.println("后退(全向,wave)");}
    else if (cmd=="LEFT")         {mode=2; moveMode=1; moveSign=+1; Serial.println("原地左转(wave)");}
    else if (cmd=="RIGHT")        {mode=2; moveMode=1; moveSign=-1; Serial.println("原地右转(wave)");}
    else if (cmd=="TROT")  {mode=1; moveMode=0; moveSign=+1; Serial.println("Trot前进");}
    else if (cmd=="TBACK") {mode=1; moveMode=0; moveSign=-1; Serial.println("Trot后退");}
    else if (cmd=="TLEFT") {mode=1; moveMode=1; moveSign=+1; Serial.println("原地左转(trot)");}
    else if (cmd=="TRIGHT"){mode=1; moveMode=1; moveSign=-1; Serial.println("原地右转(trot)");}
    else if (cmd=="CLIMB") {mode=3; dirSign=+1; turnBias=0;   Serial.println("爬墙(wave+磁铁时序)");}
    else if (cmd=="TESTDIR_LF") {mode=0; standAll(800); delay(500); testLegDir(0);}
    else if (cmd=="TESTDIR_LB") {mode=0; standAll(800); delay(500); testLegDir(1);}
    else if (cmd=="TESTDIR_RF") {mode=0; standAll(800); delay(500); testLegDir(2);}
    else if (cmd=="TESTDIR_RB") {mode=0; standAll(800); delay(500); testLegDir(3);}
    else if (cmd=="STRAFE_LEFT")   {mode=5; moveDirDeg=90.0;  omniGait=2; Serial.println("左移(全向,wave)");}
    else if (cmd=="STRAFE_RIGHT")  {mode=5; moveDirDeg=270.0; omniGait=2; Serial.println("右移(全向,wave)");}
    else if (cmd=="TSTRAFE_LEFT")  {mode=5; moveDirDeg=90.0;  omniGait=1; Serial.println("左移(全向,trot)");}
    else if (cmd=="TSTRAFE_RIGHT") {mode=5; moveDirDeg=270.0; omniGait=1; Serial.println("右移(全向,trot)");}
    else if (cmd=="SLOW")  {WAVE_RATE=0.003; TROT_RATE=0.003; Serial.println("慢放");}
    else if (cmd=="FAST")  {WAVE_RATE=0.028; TROT_RATE=0.020; Serial.println("正常速度");}
    else if (cmd=="STAND"||cmd=="STOP"){mode=0; standAll(); Serial.println("站立");}
    // 四腿独立踝补偿: TRIM_LF/LB/RF/RB <值>
    else if (cmd.startsWith("TRIM_LF ")) { LEG_TRIM[0]=constrain(cmd.substring(8).toFloat(),-30,30); if(mode==0)standAll(600); }
    else if (cmd.startsWith("TRIM_LB ")) { LEG_TRIM[1]=constrain(cmd.substring(8).toFloat(),-30,30); if(mode==0)standAll(600); }
    else if (cmd.startsWith("TRIM_RF ")) { LEG_TRIM[2]=constrain(cmd.substring(8).toFloat(),-30,30); if(mode==0)standAll(600); }
    else if (cmd.startsWith("TRIM_RB ")) { LEG_TRIM[3]=constrain(cmd.substring(8).toFloat(),-30,30); if(mode==0)standAll(600); }
    else if (cmd.startsWith("TRIM "))    {   // 兼容: 四腿同时设为同一值
      float v = constrain(cmd.substring(5).toFloat(), -30.0, 30.0);
      for(int k=0;k<4;k++) LEG_TRIM[k]=v;
      if (mode == 0) standAll(600);
    }
    // 四腿独立伸展量(mm): REACH_LF/LB/RF/RB <值>, 跨面/够不到时("踩空")用
    else if (cmd.startsWith("REACH_LF ")) { LEG_REACH[0]=constrain(cmd.substring(9).toFloat(),-25,25); if(mode==0)standAll(600); }
    else if (cmd.startsWith("REACH_LB ")) { LEG_REACH[1]=constrain(cmd.substring(9).toFloat(),-25,25); if(mode==0)standAll(600); }
    else if (cmd.startsWith("REACH_RF ")) { LEG_REACH[2]=constrain(cmd.substring(9).toFloat(),-25,25); if(mode==0)standAll(600); }
    else if (cmd.startsWith("REACH_RB ")) { LEG_REACH[3]=constrain(cmd.substring(9).toFloat(),-25,25); if(mode==0)standAll(600); }
    else if (cmd=="MAGNET_ON")  {magAllOn();  Serial.println("四磁铁错峰吸附");}
    else if (cmd=="MAGNET_OFF") {magAllOff(); Serial.println("四磁铁错峰释放");}
    else if (cmd=="MAG_LF_ON") {digitalWrite(MAG_LF,HIGH);} else if (cmd=="MAG_LF_OFF"){digitalWrite(MAG_LF,LOW);}
    else if (cmd=="MAG_LB_ON") {digitalWrite(MAG_LB,HIGH);} else if (cmd=="MAG_LB_OFF"){digitalWrite(MAG_LB,LOW);}
    else if (cmd=="MAG_RF_ON") {digitalWrite(MAG_RF,HIGH);} else if (cmd=="MAG_RF_OFF"){digitalWrite(MAG_RF,LOW);}
    else if (cmd=="MAG_RB_ON") {digitalWrite(MAG_RB,HIGH);} else if (cmd=="MAG_RB_OFF"){digitalWrite(MAG_RB,LOW);}
    else if (cmd=="PUMP_ON")    {digitalWrite(PUMP_PIN,HIGH);Serial.println("气泵开");}
    else if (cmd=="PUMP_OFF")   {digitalWrite(PUMP_PIN,LOW); Serial.println("气泵关");}
    else if (cmd=="ACT_EXTEND") {digitalWrite(ACT_IN1,HIGH);digitalWrite(ACT_IN2,LOW); Serial.println("推杆伸");}
    else if (cmd=="ACT_RETRACT"){digitalWrite(ACT_IN1,LOW); digitalWrite(ACT_IN2,HIGH);Serial.println("推杆缩");}
    else if (cmd=="ACT_STOP")   {actuatorStop(); Serial.println("推杆停");}
  }

  if (lastAdjMs && millis() - lastAdjMs > ADJ_TIMEOUT) {
    bool wasActive = false;
    for (int i=0;i<4;i++){ if (zOff[i]!=0) wasActive=true; zOff[i]=0; }
    lastAdjMs = 0;
    if (wasActive && mode==0) standAll(800);
  }

  bool pressed = (digitalRead(BOOT_PIN)==LOW);
  static unsigned long lastMs = 0;
  static int bootIdx = 0;   // 0=站立 1=trot 2=wave 3=左移测试 4=右移测试 (跳过CLIMB,避免误触发磁铁)
  if (pressed && !lastPressed && (millis()-lastMs>300)) {
    lastMs = millis();
    bootIdx = (bootIdx+1) % 5;
    dirSign=+1; turnBias=0;
    moveMode=0; moveSign=+1;
    if (bootIdx==0){ mode=0; standAll(); Serial.println("[BOOT] 站立"); }
    else if (bootIdx==1){ mode=1; Serial.println("[BOOT] Trot前进"); }
    else if (bootIdx==2){ mode=2; Serial.println("[BOOT] Wave前进"); }
    else if (bootIdx==3){ mode=5; moveDirDeg=90.0;  omniGait=2; Serial.println("[BOOT] 左移测试(全向)"); }
    else               { mode=5; moveDirDeg=270.0; omniGait=2; Serial.println("[BOOT] 右移测试(全向)"); }
  }
  lastPressed = pressed;

  if (mode==1) gaitStep(1);
  else if (mode==2) gaitStep(2);
  else if (mode==3) climbStep();
  else if (mode==5) omniStep(moveDirDeg, omniGait);
}

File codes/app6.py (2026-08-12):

from flask import Flask, render_template_string, jsonify, Response
import serial
import cv2
import cv2.aruco as aruco
import threading
import time

app = Flask(__name__)

SERIAL_PORT = '/dev/ttyUSB0'
SERIAL_BAUD = 115200
esp = None
serial_lock = threading.Lock()
serial_connected = False
last_reconnect_attempt = 0
RECONNECT_INTERVAL = 2.0   # 秒, 断线后多久重试一次

def open_serial():
    """尝试打开串口, 成功返回True。失败不抛异常, 只记录状态。"""
    global esp, serial_connected
    try:
        if esp is not None:
            try: esp.close()
            except Exception: pass
        esp = serial.Serial(SERIAL_PORT, SERIAL_BAUD, timeout=0.1)
        serial_connected = True
        print(f"[串口] 已连接 {SERIAL_PORT}")
        return True
    except Exception as e:
        serial_connected = False
        print(f"[串口] 连接失败: {e}")
        return False

def ensure_serial():
    """确保串口可用, 断线时按节流频率自动重试, 不阻塞太久"""
    global last_reconnect_attempt
    if serial_connected:
        return True
    now = time.time()
    if now - last_reconnect_attempt < RECONNECT_INTERVAL:
        return False
    last_reconnect_attempt = now
    return open_serial()

open_serial()   # 启动时先尝试一次

camera = cv2.VideoCapture(0, cv2.CAP_V4L2)
camera.set(cv2.CAP_PROP_FRAME_WIDTH, 640)
camera.set(cv2.CAP_PROP_FRAME_HEIGHT, 480)
camera.set(cv2.CAP_PROP_BUFFERSIZE, 1)
camera.set(cv2.CAP_PROP_FPS, 15)

# ===== ArUco 追踪配置 =====
TARGET_ID       = 0
CENTER_DEADZONE = 0.15
STOP_SIZE_RATIO = 0.85
CMD_INTERVAL    = 0.5
LOST_TIMEOUT    = 1.0

DICT = aruco.getPredefinedDictionary(aruco.DICT_4X4_50)
detector = aruco.ArucoDetector(DICT, aruco.DetectorParameters())

# ===== 共享状态 =====
auto_mode = False
auto_status = "手动"
gait = "wave"
frame_lock = threading.Lock()
latest_frame = None

last_cmd = None
last_cmd_time = 0
last_seen_time = 0

GAIT_MAP = {
    "wave": {"FWD":"BACK","BACK":"FWD","LEFT":"LEFT","RIGHT":"RIGHT",
             "STRAFE_LEFT":"STRAFE_LEFT","STRAFE_RIGHT":"STRAFE_RIGHT"},
    "trot": {"FWD":"TROT","BACK":"TBACK","LEFT":"TLEFT","RIGHT":"TRIGHT",
             "STRAFE_LEFT":"TSTRAFE_LEFT","STRAFE_RIGHT":"TSTRAFE_RIGHT"},
}

def raw_send(s):
    """线程安全的底层串口写(ADJ高频指令与普通指令共用)
       断线时自动尝试重连; 写入失败不抛异常, 只标记断线, 由下次调用触发重连"""
    global serial_connected
    if not ensure_serial():
        return False   # 仍未连上, 静默放弃这条指令(避免刷屏报错)
    with serial_lock:
        try:
            esp.write((s + '\n').encode())
            return True
        except Exception as e:
            serial_connected = False
            print(f"[串口] 写入失败, 标记断线待重连: {e}")
            return False

def send(cmd, force=False):
    global last_cmd, last_cmd_time
    real = GAIT_MAP[gait].get(cmd, cmd)
    now = time.time()
    if not force and real == last_cmd and now - last_cmd_time < CMD_INTERVAL:
        return True   # 去重跳过, 不算失败
    ok = raw_send(real)
    last_cmd = real
    last_cmd_time = now
    return ok

# ===== 姿态平衡控制器 (pid_ctrl.py) =====
balance_ctrl = None
balance_err = ""
try:
    from pid_ctrl import AttitudeController
    balance_ctrl = AttitudeController(raw_send, kp=1.5, ki=0.0, kd=0.08)
except Exception as e:
    balance_err = str(e)   # IMU没接好等情况, 网页按钮会提示

def camera_loop():
    global latest_frame, auto_status, last_seen_time
    while True:
        ok, frame = camera.read()
        if not ok:
            time.sleep(0.05)
            continue
        h, w = frame.shape[:2]

        gray = cv2.cvtColor(frame, cv2.COLOR_BGR2GRAY)
        corners, ids, _ = detector.detectMarkers(gray)
        if ids is not None:
            aruco.drawDetectedMarkers(frame, corners, ids)

        if auto_mode:
            decision = "SEARCH"
            found = False
            if ids is not None:
                for i, mid in enumerate(ids.flatten()):
                    if mid == TARGET_ID:
                        found = True
                        c = corners[i][0]
                        cx = c[:, 0].mean(); cy = c[:, 1].mean()
                        size = max(c[:,0].max()-c[:,0].min(),
                                   c[:,1].max()-c[:,1].min())
                        offset = (cx - w/2) / (w/2)
                        size_ratio = size / w

                        if size_ratio > STOP_SIZE_RATIO:
                            decision = "ARRIVED"; send("STAND")
                        elif offset < -CENTER_DEADZONE:
                            decision = "LEFT"; send("LEFT")
                        elif offset > CENTER_DEADZONE:
                            decision = "RIGHT"; send("RIGHT")
                        else:
                            decision = "FWD"; send("FWD")

                        cv2.drawMarker(frame,(int(cx),int(cy)),(0,0,255),
                                       cv2.MARKER_CROSS,24,2)
                        last_seen_time = time.time()
                        break
            if not found and time.time()-last_seen_time > LOST_TIMEOUT:
                decision = "LOST"; send("STAND")

            auto_status = decision
            cv2.putText(frame, "AUTO: "+decision, (10,34),
                        cv2.FONT_HERSHEY_SIMPLEX, 1.0, (0,255,0), 2)
        else:
            cv2.putText(frame, "MANUAL / "+gait.upper(), (10,34),
                        cv2.FONT_HERSHEY_SIMPLEX, 1.0, (200,200,200), 2)

        # 平衡状态叠加
        if balance_ctrl and balance_ctrl.running:
            s = balance_ctrl.status
            cv2.putText(frame, f"BAL r={s['roll']:+.1f} p={s['pitch']:+.1f}",
                        (10, h-14), cv2.FONT_HERSHEY_SIMPLEX, 0.7, (0,200,255), 2)

        with frame_lock:
            latest_frame = frame
        time.sleep(0.03)

threading.Thread(target=camera_loop, daemon=True).start()

def generate_frames():
    while True:
        with frame_lock:
            f = latest_frame
        if f is None:
            time.sleep(0.05); continue
        _, buf = cv2.imencode('.jpg', f, [cv2.IMWRITE_JPEG_QUALITY, 60])
        yield (b'--frame\r\nContent-Type: image/jpeg\r\n\r\n'
               + buf.tobytes() + b'\r\n')
        time.sleep(0.05)
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
